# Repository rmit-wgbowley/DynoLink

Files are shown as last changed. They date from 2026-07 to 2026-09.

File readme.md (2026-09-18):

<!--
Colors:
FFFFFF - Pure white
e01e37 - Bold crimson-red 

Hi,
This was my first project on the race team,
so I'm not sure if it's yours — but if it is:

Just take it seriously and you'll be fine. If
you don't want to do the work, just tell someone.
We're all here to have fun, not to make it feel
like a job.

— William Bowley

P.S: Thanks for inspecting the `.md` or downloading the DynoLink repository `▽`ʃ♡
-->

<div align="center">
  <table>
    <tr>
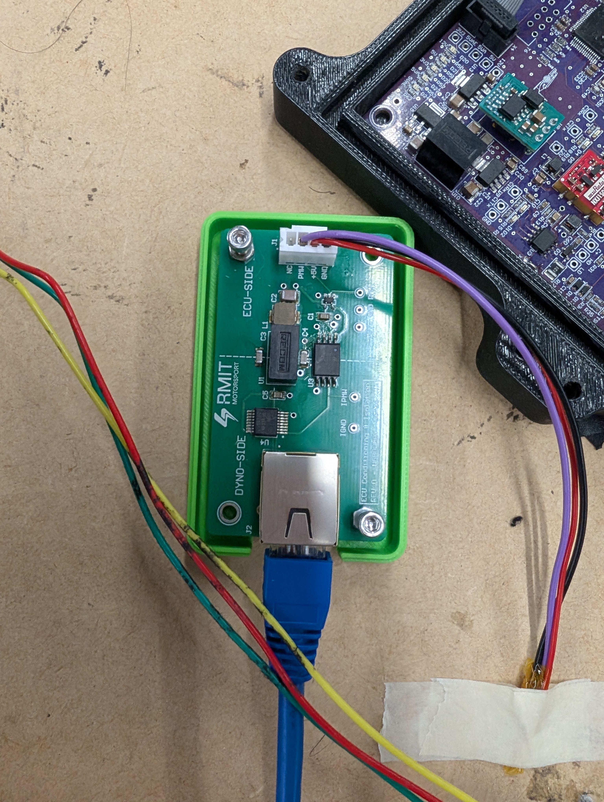
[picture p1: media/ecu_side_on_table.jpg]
ECU-Side Board
      <td></td>
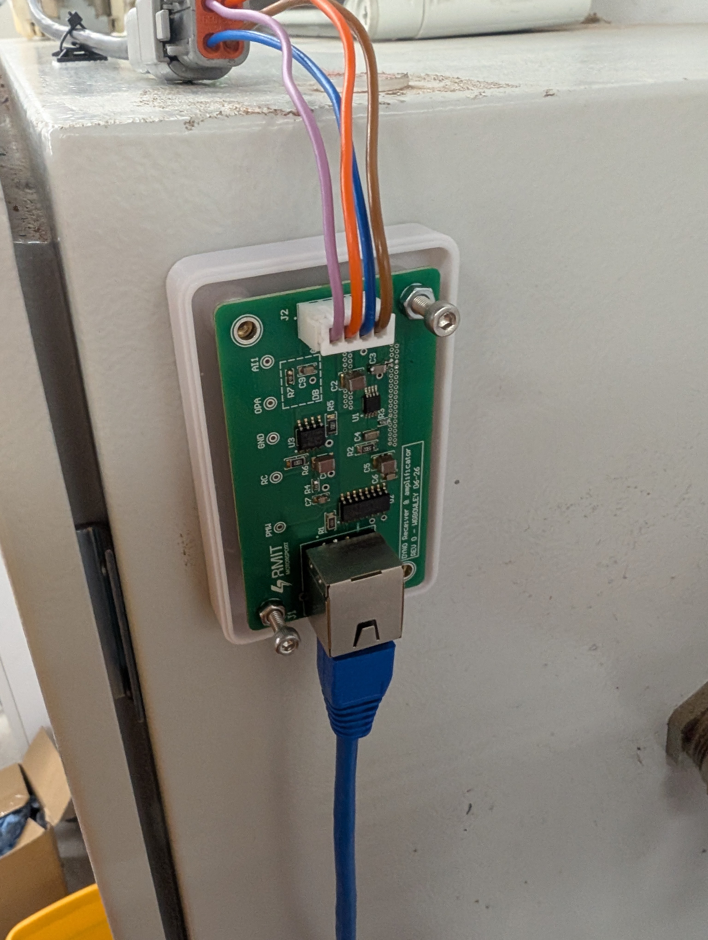
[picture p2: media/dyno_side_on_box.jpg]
Dyno-Side Board
      <td></td>
    </tr>
    <tr>
      <td><em>ECU-Side Board on table</em></td>
      <td><em>Dyno-Side Board on DCS800</em></td>
    </tr>
  </table>
</div>

### Overview

The RMIT dyno setup consists of two systems: the dyno controller panel (DCS800) and the r19e ECU. This allows the vehicle's powertrain system to be validated before implementation. 
The ECU controls the load motor and HV system. 
However, for this test setup, it is also meant to transmit a `0-3.3 V` PWM signal to control the dyno motor RPM. 
This allows a lookup table to be used to ramp up the dyno motor (a former elevator motor) RPM in an arbitrary function.

#### Objectives

```
- [x] Safely interface a 3.3 V STM32 PWM output with a 0–10 V dyno controller input.
- [x] Provide galvanic isolation between the ECU and dyno controller.
- [ ] Validate the signal is passed from the ECU to the dyno controller.
- [ ] Maintain signal integrity over a ~6 m cable run while the dyno is operating.
```

> *(Note). `[ ]` Not started. `[/]` In progress. `[x]` Complete.*

---

### Control Strategy

The 2026 dyno setup uses speed control on the dyno side and torque control on the load motor. 
This allows a lookup table to be used to ramp up the dyno RPM to model RPM vs torque. 
For example, the dyno-side RPM over time could be modelled as this arbitrary function:

$$ RPM(t) = \frac{A}{2B}(1-\cos(\frac{\pi t}{t_{total}})), \quad RPM(t) \in [0, dyno_{max}] $$

Where `A` is the target RPM at the load side, `B` is the gearing ratio between the dyno motor and load motor, and `t_total` is the total time to reach that requested RPM. 
The requested RPM then needs to be converted to duty cycle:

$$ DC(t) = (\frac{C \times RPM(t)}{2})(\frac{3.3}{5})(\frac{100}{3.3})$$
$$ DC(t) = 10C \times RPM(t), \quad DC(t) \in [0, 100]$$

And then it would simply be transformed into a simple lookup table, assuming `C` is the dyno controller input scaling factor `(V/RPM)` after the 2× amplification stage.

<br>

The dyno has a `200 kΩ` input impedance (AI1), an analog range of `0–10 V` with a linear factor of `5 mV/RPM`, and a maximum safe RPM of `1800` at the dyno-side motor. 
The r26 powertrain has a gearing of `1:12.81`. Driving frequency table (ARR), output ripple at the dyno, and duty-cycle resolution trade-offs can be found [`here`](./domain/readme.md).

| Step | Time (s) | ECU Duty Cycle (%) | Dyno Controller Input (V) | Target Dyno (RPM) | Target Load (RPM) |
| :--- | :---: | :---: | :---: | :---: | :---: |
| 0 | 0.00 | 0.00 | 0.0  | 0  | 0 |
| 1 | 0.25 | 0.26 | 0.03 | 5  | 64 |
| 2 | 0.50 | 0.98 | 0.10 | 20 | 256 |
| 3 | 0.75 | 1.95 | 0.20 | 39 | 500 |
| 4 | 1.00 | 2.93 | 0.29 | 59 | 755 |
| 5 | 1.25 | 3.64 | 0.36 | 73 | 935 |
| 6 | 1.50 | 3.90 | 0.39 | 78 | 999 |

*Figure 1: Example profile parameters configured for a real-time `1.5-second` window with time steps of `250 ms` using `A = 1000`, `B = 12.81`, and `c = 0.005`.*

> The program used to generate that table can be found [`here`](./domain/example_profiles.py)

However, for the real system, race day data is used to model the dynamic torque loading on the load motor.

---

### High-level Topology

The dyno controller and r19e ECU are approximately `2-4 meters` apart and operate at different voltage levels (`0-3.3V` vs `0-10V`). An ECU conditioning and isolation board is used on one end, and a dyno receiver and amplification board on the other. Due to the electrical noise produced by the dyno motors, an `RS-422` differential link was used.

```
Interface (2.54mm Pitch Male Header)
ECU PWM Source (Digital 3.3 V - PB13, TIM1_CHN1, STM32F405RGT6)
                    ↓

Interface (JST XH 4-pin 2.5mm)
ECU Side (3.3 V logic / 5 V domain) (Conditioning / Isolation)
--------------------------------------------
Schmitt Trigger (Edge Conditioning)
    ↓
Digital Isolator (Isolates the PWM Signal) ← (Isolated 5 V Domain)
    ↓
RS-422 Driver (A/B Differential Pair)
-------------------------------------------- 
Interface Socket (RJ45)
                    ↓

CAT 5/6 Cable
--------------------------------------------
Twisted Pairs: (+Signal, -Signal)
--------------------------------------------
                    ↓

Interface Socket (RJ45)
DYNO Side (5 / 10 V domain) (Receiver / Amplification) 
--------------------------------------------
RS-422 Receiver (Differential Input, Rejects Noise) ← (5 V LDO)
    ↓
RC Low-Pass Filter (50 Hz) (PWM to DC Voltage Conversion)
NOTE:
Ripple magnitude depends on PWM frequency,
filter capacitance, and filter resistance.
    ↓
Op-Amp 2× Gain (Non-Inverting) (Scales to 0–10V ADC Input Range) ← 10 V Line
--------------------------------------------- 
Interface (JST XH 4-pin 2.5mm)
                    ↓
Interface (4-pin Barrel Jack) (Unknown Specifics)
DYNO Controller (Analog 10V Input)
```

---

### Case Design

<p align="center">
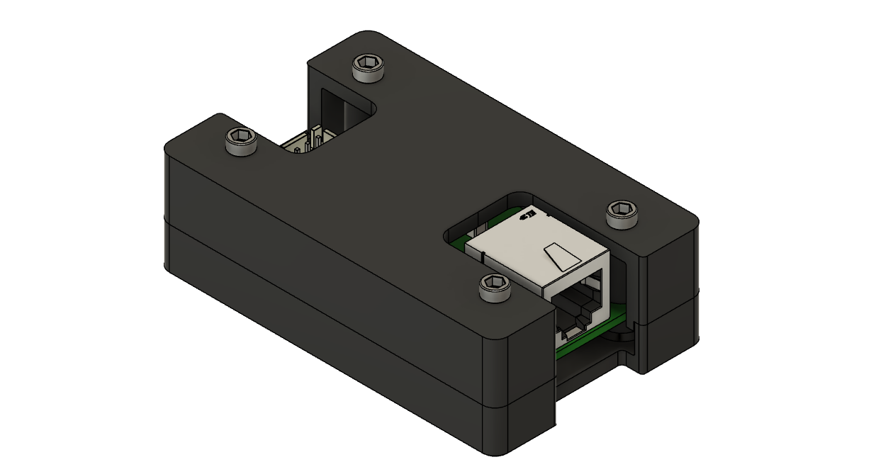
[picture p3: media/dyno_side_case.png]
Dyno-side case render
  
</p>
<p align="center">
  <em>Housing design (identical for both ECU-side and Dyno-side boards)</em>
</p>

Case design files: [`Available here (Fusion source files)`](domain/03_cad/)

```
- Same case size and external design for both boards — only internal PCBs differ
- IGES format included for users without Fusion
- 4× M3 inserts for mounting PCB and top housing
- Velcro recommended to secure the housing to the test bench
```

---

### Documentation

Design notes, validation results, design iterations, and implementation 
decisions are documented in the repository [`issues`](https://github.com/rmit-wgbowley/dyno-boards/issues).

#### Tags

```
Project Progress:
----------------------------------------------------
LX → Documentation and project structure
L0 → Review and analysis of reference designs
L1 → System level design, topology and interfaces
L2 → Detailed design & prototyping
L3 → Testing & Validation of prototype
----------------------------------------------------
```

<br>

```
Miscellaneous:
----------------------------------------------------
DS → De-scoped Feature, De-scoped Analysis
AC → Architectural Change
----------------------------------------------------
```

---

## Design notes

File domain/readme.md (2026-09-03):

### Output Dynamics Based on Frequency Changes (FOR STM32F405RGT6)

---

### Assumed Configuration:
> - PSC = 0
> - RC Characteristics: 2 kΩ, 1.6 µF
> - Clock Speed: 160 MHz on TIM1_CH1N (APB2)
> - APB2 (Scale of 2x) → PCLK2 (80 MHz) → 160 MHz
> - These values will be different if R7 and C9 are populated with (47 Ω | 100 nf, etc.)

---

### Initial Calibration Row (10 kHz)

| RPM Step (at Dyno) | ARR | Frequency | Output Ripple (After 2x @ DYNO) |
|---|-----|---|---|
| 0.625 rpm | 15999 | 10.000 kHz | 156.080 mV |

---

### Main Table (0.2 rpm Resolution)

| RPM Step (at Dyno) | ARR | Frequency | Output Ripple (After 2x @ DYNO) |
|---|-----|---|---|
| 0.200 rpm | 9999 | 16.000 kHz | 97.656 mV |
| 0.400 rpm | 4999 | 32.000 kHz | 48.828 mV |
| 0.600 rpm | 3332 | 48.005 kHz | 32.549 mV |
| 0.800 rpm | 2499 | 64.000 kHz | 24.414 mV |
| 1.000 rpm | 1999 | 80.000 kHz | 19.531 mV |
| 1.200 rpm | 1666 | 95.981 kHz | 16.279 mV |
| 1.400 rpm | 1428 | 111.966 kHz | 13.955 mV |
| 1.600 rpm | 1249 | 128.000 kHz | 12.207 mV |
| 1.800 rpm | 1110 | 144.014 kHz | 10.850 mV |
| 2.000 rpm | 999 | 160.000 kHz | 9.766 mV |
| 2.200 rpm | 908 | 176.018 kHz | 8.877 mV |
| 2.400 rpm | 832 | 192.077 kHz | 8.135 mV |
| 2.600 rpm | 768 | 208.062 kHz | 7.510 mV |
| 2.800 rpm | 713 | 224.090 kHz | 6.973 mV |
| 3.000 rpm | 666 | 239.880 kHz | 6.514 mV |
| 3.200 rpm | 624 | 256.000 kHz | 6.104 mV |
| 3.400 rpm | 587 | 272.109 kHz | 5.742 mV |
| 3.600 rpm | 555 | 287.770 kHz | 5.430 mV |
| 3.800 rpm | 525 | 304.183 kHz | 5.137 mV |
| 4.000 rpm | 499 | 320.000 kHz | 4.883 mV |
| 4.200 rpm | 475 | 336.134 kHz | 4.648 mV |
| 4.400 rpm | 454 | 351.648 kHz | 4.443 mV |
| 4.600 rpm | 434 | 367.816 kHz | 4.248 mV |
| 4.800 rpm | 416 | 383.693 kHz | 4.072 mV |
| 5.000 rpm | 399 | 400.000 kHz | 3.906 mV |
| 5.200 rpm | 384 | 415.584 kHz | 3.760 mV |
| 5.400 rpm | 369 | 432.432 kHz | 3.613 mV |
| 5.600 rpm | 356 | 448.179 kHz | 3.486 mV |
| 5.800 rpm | 344 | 463.768 kHz | 3.369 mV |
| 6.000 rpm | 332 | 480.480 kHz | 3.252 mV |
| 6.200 rpm | 322 | 495.356 kHz | 3.154 mV |
| 6.400 rpm | 311 | 512.821 kHz | 3.047 mV |
| 6.600 rpm | 302 | 528.053 kHz | 2.959 mV |
| 6.800 rpm | 293 | 544.218 kHz | 2.871 mV |
| 7.000 rpm | 285 | 559.441 kHz | 2.793 mV |
| 7.200 rpm | 277 | 575.540 kHz | 2.715 mV |
| 7.400 rpm | 269 | 592.593 kHz | 2.637 mV |
| 7.600 rpm | 262 | 608.365 kHz | 2.568 mV |
| 7.800 rpm | 255 | 625.000 kHz | 2.500 mV |
| 8.000 rpm | 249 | 640.000 kHz | 2.441 mV |
| 8.200 rpm | 243 | 655.738 kHz | 2.383 mV |
| 8.400 rpm | 237 | 672.269 kHz | 2.324 mV |
| 8.600 rpm | 232 | 686.695 kHz | 2.275 mV |
| 8.800 rpm | 226 | 704.846 kHz | 2.217 mV |
| 9.000 rpm | 221 | 720.721 kHz | 2.168 mV |
| 9.200 rpm | 216 | 737.327 kHz | 2.119 mV |
| 9.400 rpm | 212 | 751.174 kHz | 2.080 mV |
| 9.600 rpm | 207 | 769.231 kHz | 2.031 mV |
| 9.800 rpm | 203 | 784.314 kHz | 1.992 mV |
| 10.000 rpm | 199 | 800.000 kHz | 1.953 mV |

---

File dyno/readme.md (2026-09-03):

### Dyno Side Topology & Components

```
Interface (RJ45) 
ECU Side (5V PMW twisted pairs: +signal, -signal)
                    ↓
Interface (RJ45) 
DYNO Side (5/10 V domain) (receiver / amplification) 
--------------------------------------------
5V Line ← (TPS7A4901, 14 ms start-up, 0.1–0.5 W | R1 = 10 kΩ & R2 = 33 kΩ)
    ↓
RS-422 receiver (Differential input, rejects noise) (AM26LS32AIN)
    ↓
RC low-pass filter (50 Hz) (PWM to DC voltage conversion)
    ↓
Op-amp 2× Gain (Scales to 0–10 V) (TLV272) ← 10 V Line
---------------------------------------------
Interface (JST XH 4-pin 2.5 mm)
                    ↓
Interface (4-pin barrel jack) (Unknown Specifics)
DYNO Controller (Analog 10V Input)
```

---

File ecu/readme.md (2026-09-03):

### ECU-side Topology & Components

```
Interface (2.54mm Pitch Male Header)
ECU PWM Source (Digital 3.3 V @ 10 kHz - PB13, tim1_CHN1, STM32F405RGT6)
                    ↓
Interface (JST XH 4-pin 2.5mm)
ECU Side (3.3 V logic / 5 V domain) (conditioning / isolation)
--------------------------------------------
Schmitt trigger (Cleans up the signal edge) (SN74LVC1G17)
    ↓
Digital Isolator (Isolates the PWM signal) (ISO7720) <- RFM-0505S (isolated 5 V)
    ↓
RS-422 Driver (A/B differential pair) (AM26LS31)
--------------------------------------------
Interface Socket (RJ45) (twisted pairs: +signal, -signal)
                    ↓
Interface (RJ45) 
DYNO Side (5/10 V domain) (receiver / amplification) 
```

---

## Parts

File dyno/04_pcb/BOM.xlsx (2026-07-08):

Line # | Name | Description | Designator | Revision ID | Revision Status | Quantity | Manufacturer 1 | Manufacturer Part Number 1 | Manufacturer Lifecycle 1 | Supplier 1 | Supplier Part Number 1 | Supplier Unit Price 1 | Supplier Subtotal 1
 | 1-1734264-1 | 1-1734264-1 Conn Modular Jack F 8 POS 1.02mm Solder RA Thru-Hole 8 Terminal 1 Port Cat 5 Box/Tray | J1 | CMP-03790-45268370-1 | Up to date | 1 | TE Connectivity | 1-1734264-1 | Volume Production | Mouser | 571-1-1734264-1 | 1.73 | 1.73
 | 10nf | CAP CER 10000PF 100V X7R 0603 | C3, C4 |  |  | 2 | Murata | GCM188R72A103KA37D | Volume Production | Mouser | 81-GCM188R72A103KA7D | 0.14392 | 0.28783
 | 10uF | CAP CER 10UF 25V X5R 1210 | C2, C5 |  |  | 2 | TDK | C3225X5R1E106K250AA | Volume Production | Mouser | 810-C3225X5R1E106K | 0.80593 | 1.61
 | 100nF | 0805 100 nF 25V ±10 % Tolerance X7R Surface Mount Multilayer Ceramic Capacitor | C1, C6, C7, C9 |  |  | 4 | KYOCERA AVX | 08053C104KAT2A | Volume Production | Mouser | 581-08053C104K | 0.15831 | 0.63323
 | AM26LS32ACDR | Quadruple Differential Line Receiver, 0 TX / 4 RX, 0 to 70 degC, 16-Pin SOIC (D), Green (RoHS & no Sb/Br) | U2 | CMP-0310-00258-2 | Up to date | 1 | Texas Instruments | AM26LS32ACDR | Volume Production | Mouser | 595-AM26LS32ACDR | 1.58 | 1.58
 | C3225X7R2A155K200AB | Multilayer Ceramic Capacitors 1.5uF ±10% 100V X7R SMD 1210 | C8 | CMP-08246-005458-1 | Up to date | 1 | TDK | C3225X7R2A155K200AB | Volume Production | Mouser | 810-C3225X7R2A155K2B | 0.92107 | 0.92107
 | KTR18EZPF1000 | RES SMD 100 OHM 1% 1/4W 1206 | R1 |  |  | 1 | ROHM | KTR18EZPF1000 | Volume Production | Mouser | 755-KTR18EZPF1000 | 0.31662 | 0.31662
 | RA-3AEB103V | RES SMD 10K OHM 0.1% 1/10W 0603 | R3 |  |  | 1 | Panasonic | ERA-3AEB103V | Volume Production | Mouser | 667-ERA-3AEB103V | 0.14392 | 0.14392
 | RC0603FR-072KL | RES SMD 2K OHM 1% 1/10W 0603 | R4 |  |  | 1 | Yageo Group | RC0603FR-072KL | Volume Production | Mouser | 603-RC0603FR-072KL | 0.14392 | 0.14392
 | RC0603FR-0747RL | RES SMD 47 OHM 1% 1/10W 0603 | R7 |  |  | 1 | Yageo Group | RC0603FR-0747RL | Volume Production | Mouser | 603-RC0603FR-0747RL | 0.14392 | 0.14392
 | RC1206FR-071KL | RES SMD 1K OHM 1% 1/4W 1206 | R5, R6 |  |  | 2 | Yageo Group | RC1206FR-071KL | Volume Production | Mouser | 603-RC1206FR-071KL | 0.14392 | 0.28783
 | RC1206FR-0733KL | RES SMD 33K OHM 1% 1/4W 1206 | R2 |  |  | 1 | Yageo Group | RC1206FR-0733KL | Volume Production | Mouser | 603-RC1206FR-0733KL | 0.14392 | 0.14392
 | TLV272QDRQ1 | Automotive Catalog 550 uA/Ch, 3 MHz, Rail-to-Rail Output Operational Amplifier, 2.7 to 16 V, -40 to 125 degC, 8-pin SOIC (D8), Green (RoHS & no Sb/Br) | U3 | CMP-0272-02933-3 | Up to date | 1 | Texas Instruments | TLV272QDRQ1 | Volume Production | Mouser | 595-TLV272QDRQ1 | 1.61 | 1.61
 | TPS7A4901DGNT | None | U1 | CMP-0394-01238-3 | Up to date | 1 | Texas Instruments | TPS7A4901DGNT | Volume Production | Mouser | 595-TPS7A4901DGNT | 6.13 | 6.13

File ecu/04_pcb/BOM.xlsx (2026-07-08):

Line # | Name | Description | Designator | Revision ID | Revision Status | Quantity | Manufacturer 1 | Manufacturer Part Number 1 | Manufacturer Lifecycle 1 | Supplier 1 | Supplier Part Number 1 | Supplier Unit Price 1 | Supplier Subtotal 1
 | SN74LVC1G17QDBVRQ1 | Automotive Catalog Single Schmitt-Trigger Buffer, DBV0005A, LARGE T&R |  | CMP-0859-00050-4 | Up to date | 1 | Texas Instruments | SN74LVC1G17QDBVRQ1 | Volume Production | Mouser | 595-74LVC1G17QDBVRQ1 | 0.43175 | 0.43175
 | 08053C104KAT2A | 0805 100 nF 25V ±10 % Tolerance X7R Surface Mount Multilayer Ceramic Capacitor | C1, C5 | CMP-001-00318-1 | Up to date | 2 | KYOCERA AVX | 08053C104KAT2A | Volume Production | Mouser | 581-08053C104K | 0.15831 | 0.31662
 | C3225X5R1E106K250AA | CAP CER 10UF 25V X5R 1210 | C2 | CMP-001-00249-3 | Up to date | 1 | TDK | C3225X5R1E106K250AA | Volume Production | Mouser | 810-C3225X5R1E106K | 0.80593 | 0.80593
 | GCM31A7U2J221JX01D | Ceramic Capacitor for Automotive 220pF ±5% 630VDC U2J 1206 Paper T/R | C3, C4 | CMP-06035-026775-1 | Up to date | 2 | Murata | GCM31A7U2J221JX01D | Volume Production | Mouser | 81-GCM31A7U2J221JX1D | 0.56127 | 1.12
 | 1-1734264-1 | 1-1734264-1 Conn Modular Jack F 8 POS 1.02mm Solder RA Thru-Hole 8 Terminal 1 Port Cat 5 Box/Tray | J2 | CMP-03790-45268370-1 | Up to date | 1 | TE Connectivity | 1-1734264-1 | Volume Production | Mouser | 571-1-1734264-1 | 1.73 | 1.73
 | IHLP2020CZER220M11 | Fixed Inductors Commercial Low DCR Series 22uH 1.9A 270mΩ 20% | L1 | CMP-02424-000568-1 | Up to date | 1 | Vishay | IHLP2020CZER220M11 | Volume Production | Mouser | 70-IHLP2020CZER220M1 | 1.68 | 1.68
 | RFM-0505S | DC DC CONVERTER 5V 1W | U1 | CMP-29842-000017-1 | Up to date | 1 | Recom Power | RFM-0505S | Volume Production | Mouser | 919-RFM-0505S | 3.09 | 3.09
 | ISO7720DWV | DGTL ISO 5000VRMS 2CH GP 8SOIC | U3 | CMP-04872-000164-1 | Up to date | 1 | Texas Instruments | ISO7720DWV | Volume Production | Mouser | 595-ISO7720DWV | 5.11 | 5.11
 | AM26LS31CNSR | Quadruple Differential Line Driver, 4 TX / 0 RX, 5V, 0 to 70 degC, 16-Pin SO (NS), Green (RoHS & no Sb/Br) | U4 | CMP-0310-00483-2 | Up to date | 1 | Texas Instruments | AM26LS31CNSR | Volume Production | Mouser | 595-AM26LS31CNSR | 2.73 | 2.73

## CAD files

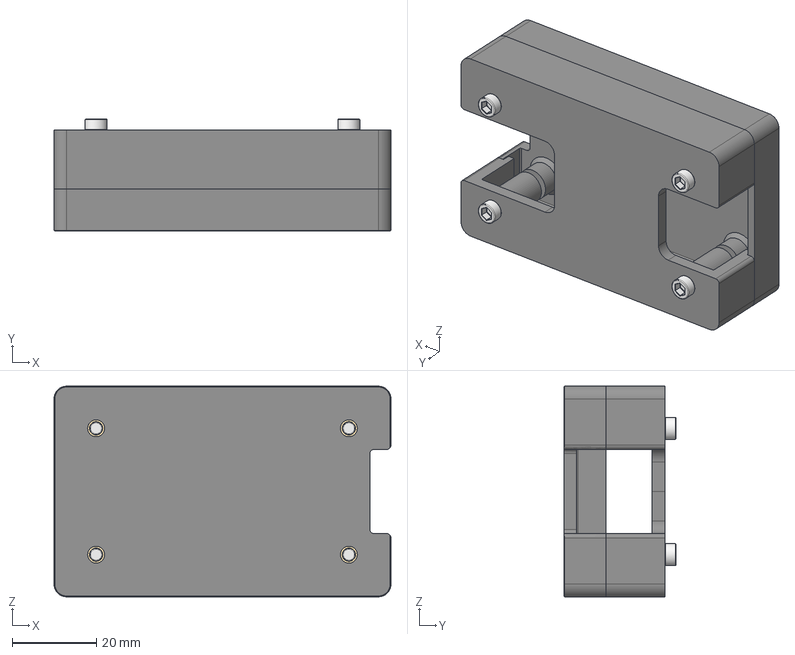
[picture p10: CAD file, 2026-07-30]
domain/03_cad/pcb_case.iges
80.0 x 26.7 x 50.0 mm

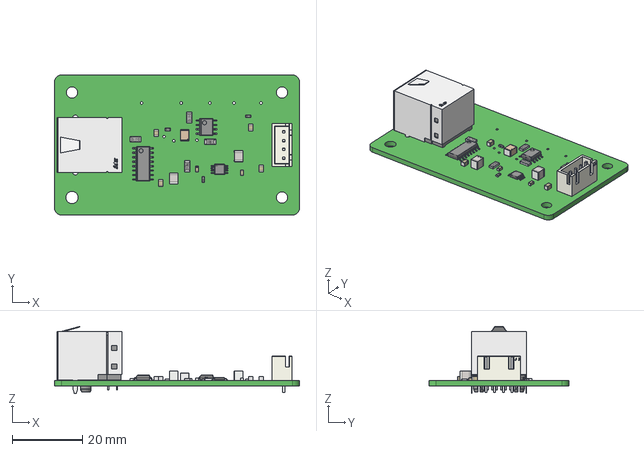
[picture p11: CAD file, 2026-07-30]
dyno/03_cad/dyno_side_interface.step
70.0 x 40.0 x 19.2 mm

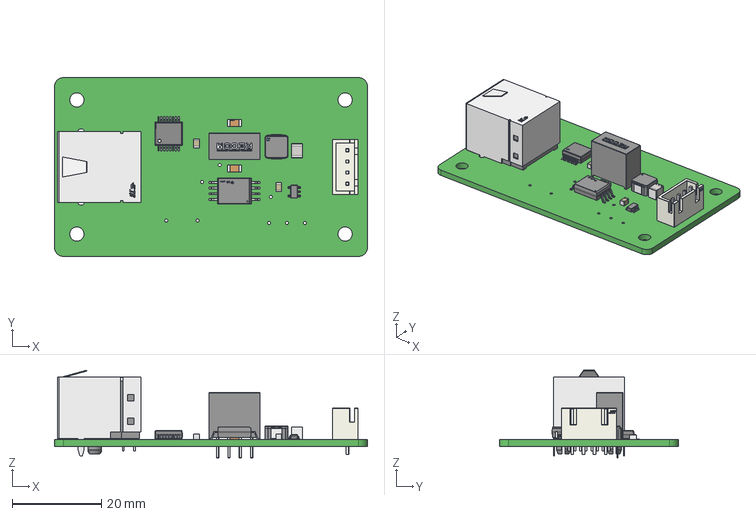
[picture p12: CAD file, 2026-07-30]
ecu/03_cad/ecu_side_interface.step
70.0 x 40.0 x 19.6 mm

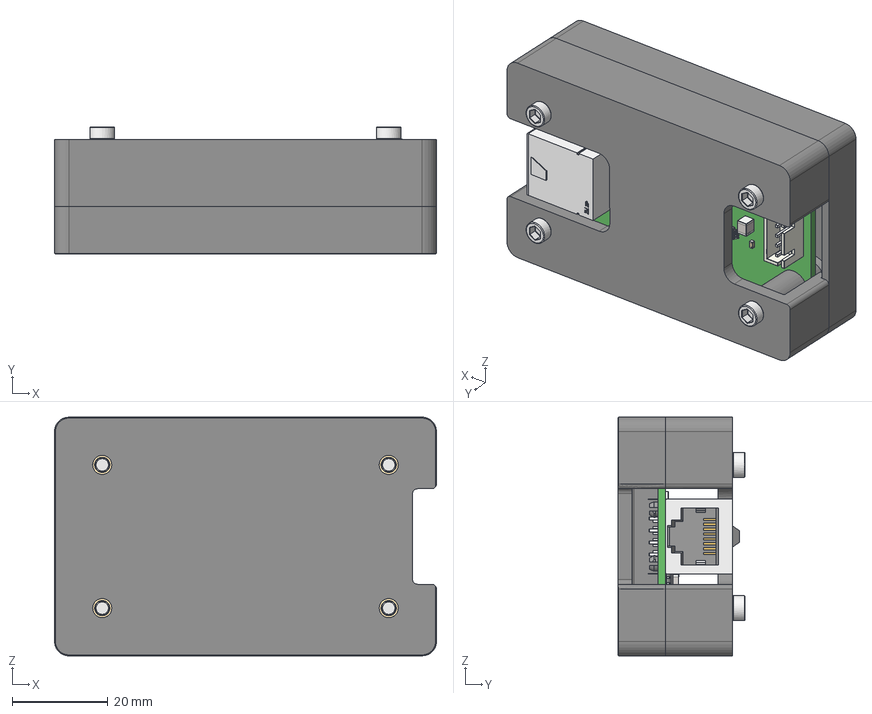
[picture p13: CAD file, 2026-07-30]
dyno/03_cad/dyno-mounted.iges
80.0 x 26.7 x 50.0 mm

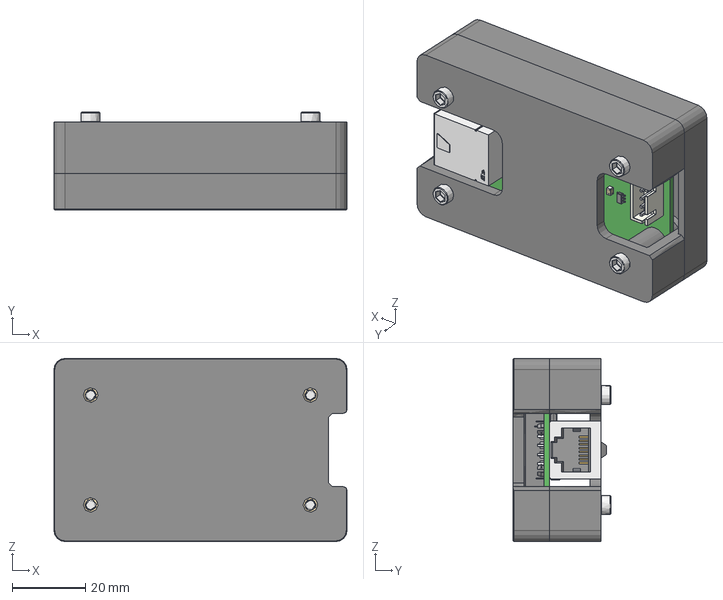
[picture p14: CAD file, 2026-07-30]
ecu/03_cad/ecu-mounted.iges
80.0 x 26.7 x 50.0 mm

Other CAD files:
domain/03_cad/pcb_case.f3z

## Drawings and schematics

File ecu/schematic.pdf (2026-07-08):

REVISION | DESCRIPTION | DATE | APPROVED | REV. SHT. DWG. NO. 1

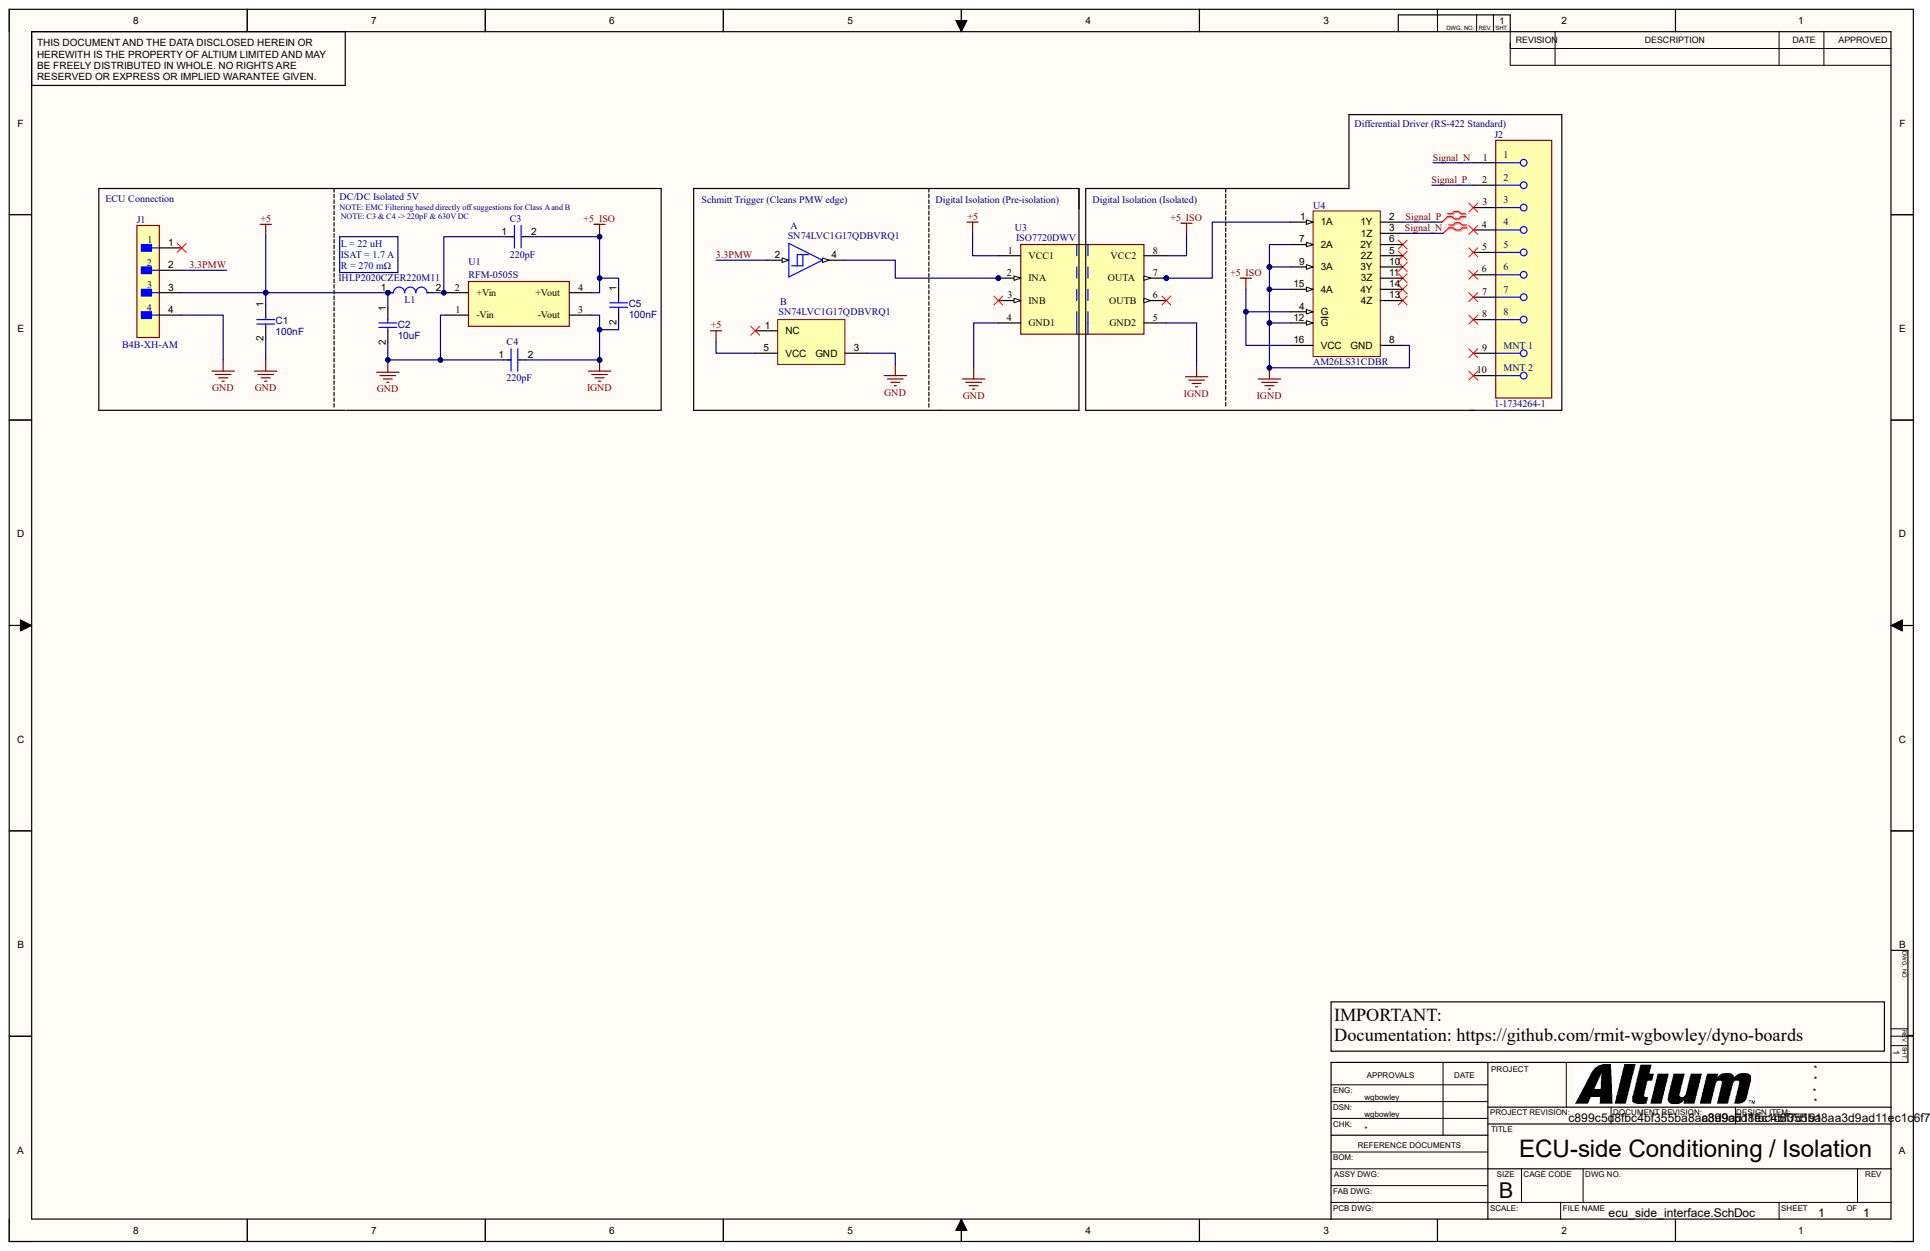
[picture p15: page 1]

THIS DOCUMENT AND THE DATA DISCLOSED HEREIN OR
HEREWITH IS THE PROPERTY OF ALTIUM LIMITED AND MAY
BE FREELY DISTRIBUTED IN WHOLE. NO RIGHTS ARE
RESERVED OR EXPRESS OR IMPLIED WARANTEE GIVEN.

Differential Driver (RS-422 Standard)

Schmitt Trigger (Cleans PMW edge)

Digital Isolation (Pre-isolation)

NOTE: EMC Filtering based directly off suggestions for Class A and B 1 2

IMPORTANT:
Documentation: https://github.com/rmit-wgbowley/dyno-boards

APPROVALS | DATE | PROJECT | * *

ENG: wgbowley
CHK: * | | TITLE ECU-side Conditioning / Isolation

DSN: wgbowley

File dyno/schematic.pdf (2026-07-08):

REVISION | DESCRIPTION | DATE | APPROVED | REV. SHT. DWG. NO. 1
IN 8 | 9

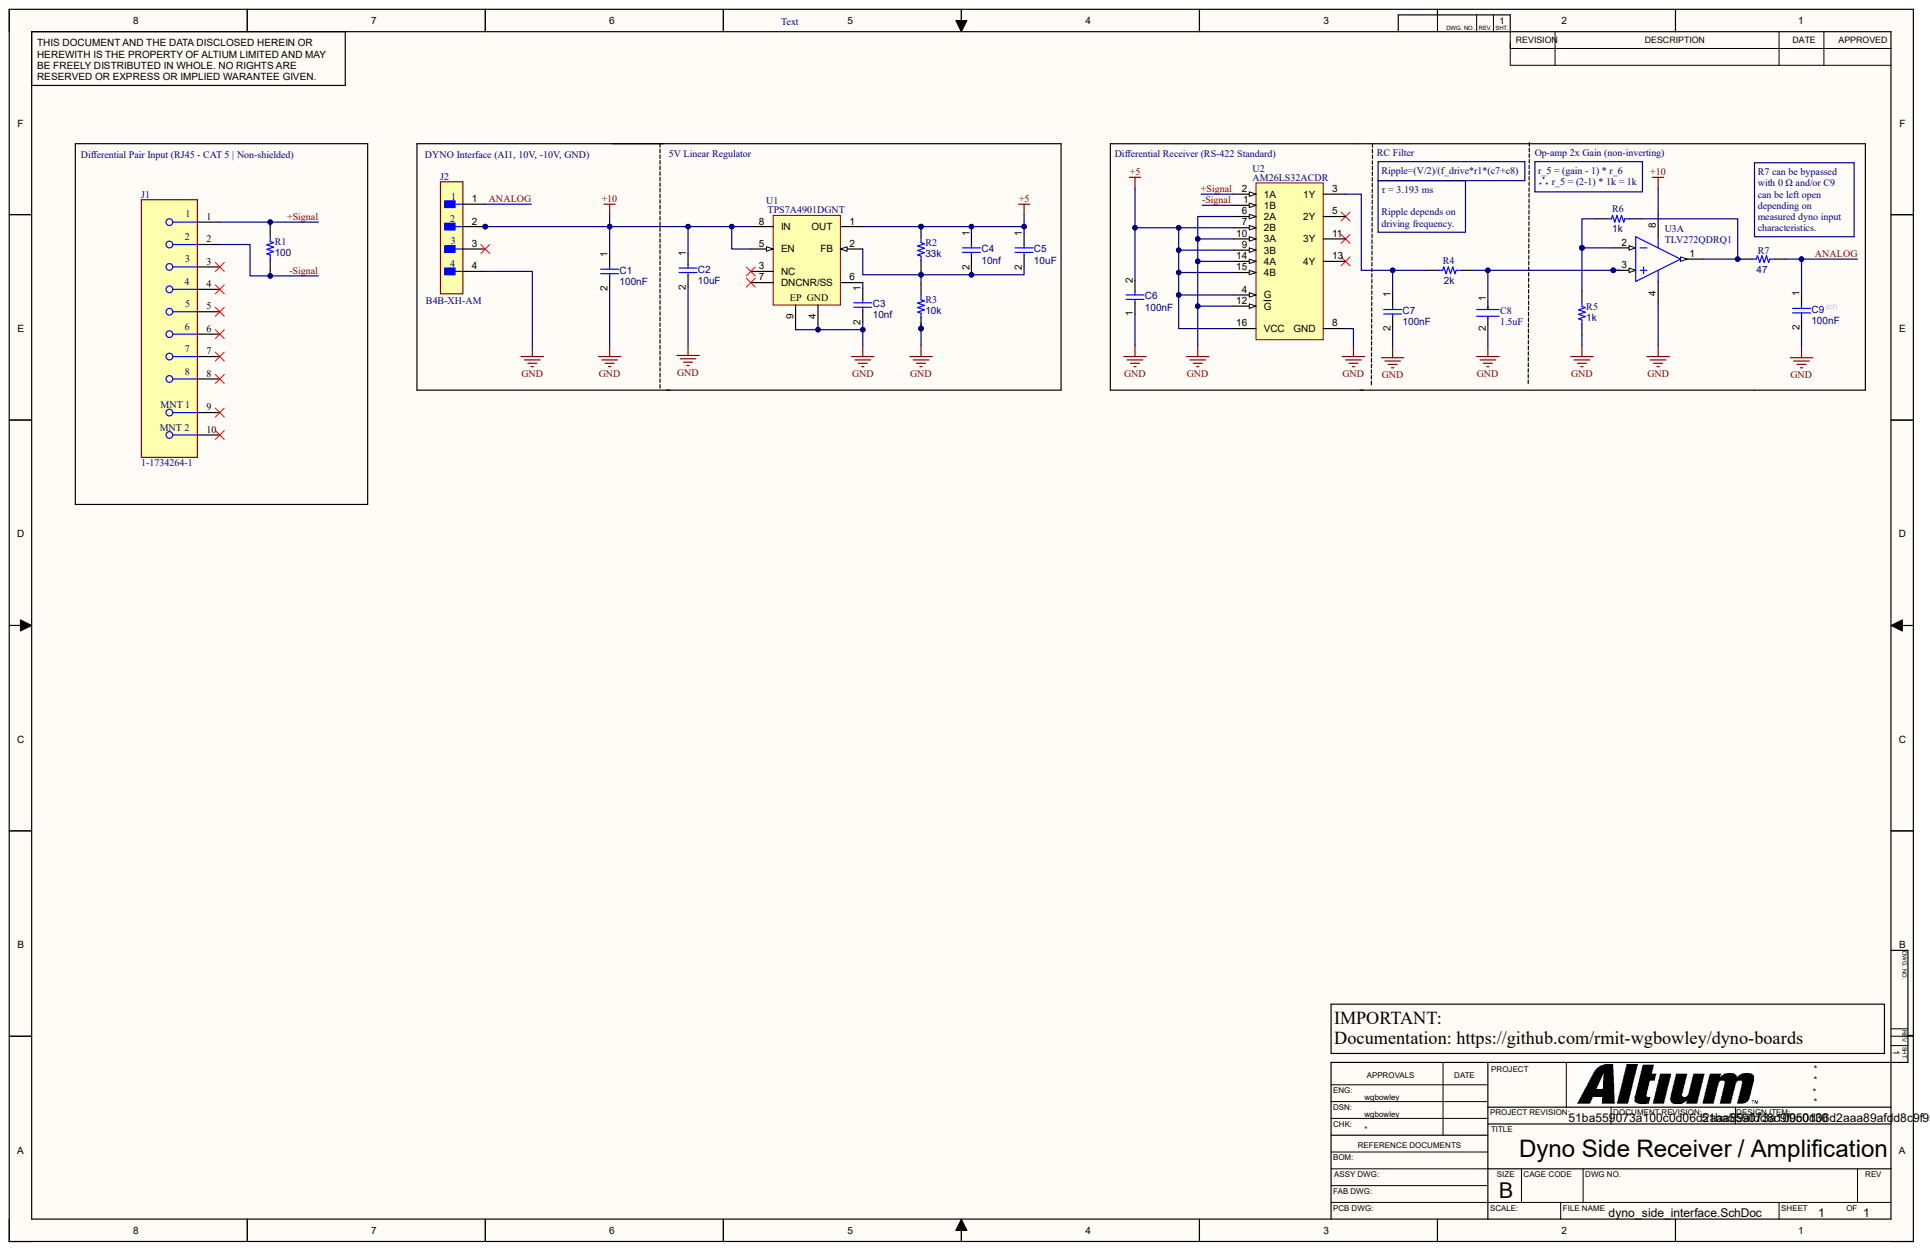
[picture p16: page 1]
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

Differential Pair Input (RJ45 - CAT 5 | Non-shielded)

R7 can be bypassed
with 0 Ω and/or C9
can be left open
depending on
measured dyno input
characteristics.

IMPORTANT:
Documentation: https://github.com/rmit-wgbowley/dyno-boards

APPROVALS | DATE | PROJECT | * *

ENG: wgbowley
CHK: * | | TITLE Dyno Side Receiver / Amplification

DSN: wgbowley

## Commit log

2026-07-05 PCB manufacturing files in (.zip -> Gerber X2 & NC drill)
    ecu & dyno side interface as zip
2026-07-08 BOM & Reorganisation
    [BOM.xlsx]
2026-07-30 Reorganize files and code improves from picounits 1.0.8
    [BOM.xlsx, dyno-mounted.iges, dyno_side_interface.step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]
